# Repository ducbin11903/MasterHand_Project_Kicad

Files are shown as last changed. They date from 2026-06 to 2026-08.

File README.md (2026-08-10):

<p align="center" width="100%">
  
</p>

<h1 align="center">MOTOR CONTROL BOARD</h1>

<p align="center" width="100%">
  <a href="/actions/workflows/ci.yaml">
    CI Badge
  </a>
</p>

<p align="center" width="100%">
    
</p>

***

<p align="center">
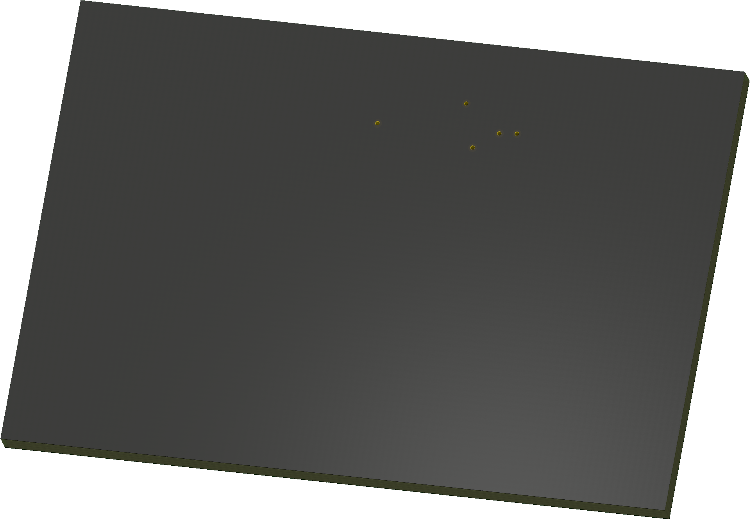
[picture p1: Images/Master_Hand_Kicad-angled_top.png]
3D Top Angled
  
&nbsp; &nbsp; &nbsp; &nbsp;
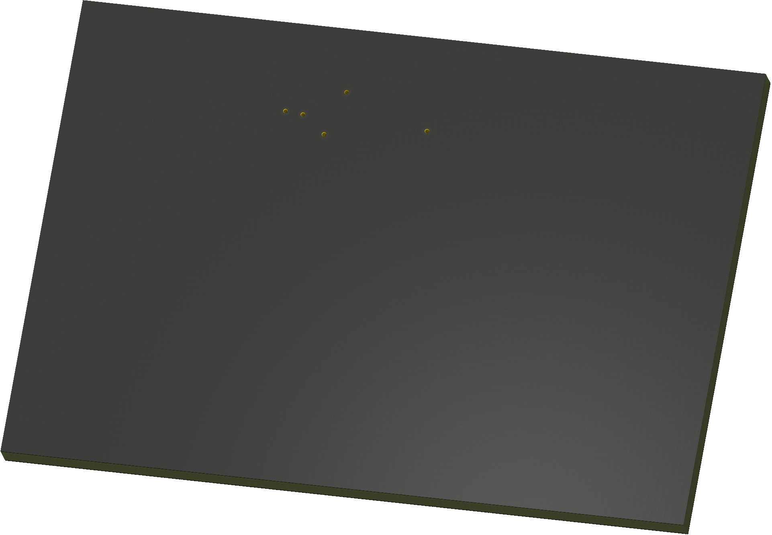
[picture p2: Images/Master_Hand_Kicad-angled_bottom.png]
3D Bottom Angled
  
</p>

***

## SPECIFICATIONS

| Parameter | Value | 
| --- | --- |
| Dimensions | 42.2 × 28.9 mm |

***

## DIRECTORY STRUCTURE

    .
    ├─ Computations       # Misc calculations
    ├─ HTML               # HTML files for generated webpage
    ├─ Images             # Pictures and renders
    │
    ├─ kibot_resources    # External resources for KiBot
    │  ├─ colors          # Color theme for KiCad
    │  ├─ fonts           # Fonts used in the project
    │  ├─ scripts         # External scripts used with KiBot
    │  └─ templates       # Templates for KiBot generated reports
    │
    ├─ kibot_yaml         # KiBot YAML config files
    ├─ KiRI               # KiRI (PCB diff viewer) files
    │
    ├─ lib                # KiCad footprint and symbol libraries
    │  ├─ 3d_models       # Component 3D models
    │  ├─ lib_fp          # Footprint libraries
    │  └─ lib_sym         # Symbol libraries
    │
    ├─ Logos              # Logos
    │
    ├─ Manufacturing      # Assembly and fabrication documents
    │  ├─ Assembly        # Assembly documents (BoM, pos, notes)
    │  │
    │  └─ Fabrication     # Fabrication documents (ZIP, notes)
    │     ├─ Drill Tables # CSV drill tables
    │     └─ Gerbers      # Gerbers
    │
    ├─ Report             # Reports for ERC/DRC
    ├─ Schematic          # PDF of schematic
    ├─ Templates          # Title block templates
    ├─ Testing
    │  └─ Testpoints      # Testpoints tables      
    │
    └─ Variants           # Outputs for assembly variants

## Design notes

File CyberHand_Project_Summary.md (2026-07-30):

# CyberHand — Motor Control & Main Board — Project Summary
_Cập nhật: 2026-07-14 · Dùng làm context cho Cowork / tài liệu repo_

---

## 1. Mô tả ngắn

Thiết kế 2 PCB cho bàn tay robot humanoid (CyberHand/CyberTUM) dùng 6 motor DC gear JGA12-N20B 6V: **Motor Control Board** và **MainBoard**, giao tiếp CAN FD + RS-422. Công cụ: **KiCad 9.0.1** + Git, hierarchy schematic, multi-channel reuse. Schematic đang vẽ theo cấu trúc sheet đánh số (vd sheet 6/19: "Power - Generation").

---

## 2. Hardware

### Motor Control Board
- 2× STM32G474RET6 (LQFP64, 170MHz), mỗi MCU điều khiển 3 motor
- 6× TB9051FTG H-bridge (VM 4.5–28V, 5A peak, AEC-Q100)
- 6× JGA12-N20B DC gear motor (stall 0.55A @6V, R cuộn ≈ 11Ω)
- 6× SS49E linear Hall sensor (ratiometric, cấp +A3V3)
- 2× TJA1051T CAN FD transceiver (VCC 5V), 120Ω termination 2 đầu bus
- 2× MAX3491 RS-422 transceiver (3.3V)
- 2× SHT31 (I2C 0x44, mỗi MCU 1 con)
- 2× USB Type-C riêng (DFU + CDC mỗi MCU) — **không nối VBUS vào rail 5V**, chỉ sense qua divider
- Crystal 8MHz HSE ×2, buzzer, 6× motor LED, battery voltage sensing

### MainBoard
- 1× STM32G474RET6, TCA9548A I2C mux, 5× FSR, ICM42688P IMU, 5× SK6812, TJA1051T, W5500 (SPI), crystal 32.768kHz

---

## 3. Power Architecture (ĐÃ CẬP NHẬT — thay thế plan LD39200 cũ)

```
LiPo 2S 7.4V / 2200mAh / 10C  (6.6–8.4V)
    │
[Polyfuse 15A] → [STPS20L60S Schottky] → [SMBJ10CA TVS]
    │
[BULK 330µF/25V polymer, ESR 20–40mΩ]  ← quyết định mới, xem mục 5
    │
    ├── +VBAT → 6× TB9051FTG VM  (+ 6× 10µF 1206 sát chân VM từng driver)
    │
    ├── U3 TPSM63603RDHR (buck module, 3A) → +5V
    │       ├── Tải 5V trực tiếp: TB9051 VCC ×6, TJA1051T ×2, LED/buzzer
    │       ├── U4 TPS62162DSG + L 2.2µH (buck 1A) → +3V3 (digital)
    │       │       └── STM32 ×2, MAX3491 ×2, SHT31, logic phụ
    │       └── U5 TLV75533PDBVR (LDO 500mA) → +A3V3 (analog)
    │               └── SS49E ×6, VDDA/VREF+ ×2, (SHT31 nếu chuyển sang analog rail)
```

Lý do kiến trúc 3 regulator: 3V3 digital từ buck (hiệu suất), A3V3 từ LDO riêng (sạch cho ADC).
SS49E ratiometric + VREF+ cùng rail A3V3 → sai số nguồn tự triệt tiêu.

### Việc còn phải xác nhận trên sheet Power - Generation (6/19)
- [ ] **FB pin TPS62162 (bản fixed 3.3V) phải nối GND** — không để floating
- [ ] Xác nhận net **F_VIN_3V3 lấy từ +5V** (TLV75533 VIN max 5.5V, không được ăn VBAT)
- [ ] Nối **VLDOIN (pin 22) của TPSM63603 → VOUT** (VOUT=5V ≥ 3.3V, tăng hiệu suất)
- [ ] Tính divider R1/R4 trên EN/SYNC cho **UVLO ≈ 6.0–6.2V** (bảo vệ LiPo, có hysteresis)
- [ ] **EN_3V3 lấy từ PG của U3** (pull-up 100k lên 5V, PG open-drain) → sequencing 5V trước, 3V3+A3V3 sau
- [ ] Điền value tụ: U3 in 2×10µF/25V + 100nF; U3 out 3–4×22µF/10V (theo bảng datasheet ứng R5/RT); VCC 1µF; CBOOT 100nF+RBOOT; U4 in 10µF/out 22µF, L1 Isat ≥ 1.5A; U5 in/out 1µF (out 10µF càng tốt)
- [ ] FB4 sau LDO: giữ thì thêm 10µF+100nF tại VDDA/VREF+; bỏ cũng được
- [ ] AGND của U3 nối PGND single-point theo layout guideline TI

---

## 4. Power Budget (ĐÃ TÍNH LẠI)

Phương pháp: I_avg = Σ Typ tại điều kiện thật; I_peak = Σ Max @T_max, chỉ tải đồng thời. Chọn regulator ≥ 1.5–2× peak.

| Rail | Nguồn | Avg (typ) | Peak (max) | Định mức | Ghi chú |
|---|---|---|---|---|---|
| VBAT 7.4V | LiPo qua protection | ~1.25A | ~3.75A (duty≤71%) / **4.6A nếu duty 100% @8.4V** | 22A (10C) | 6 motor stall = worst case |
| +5V | TPSM63603 | ~180mA | ~610mA | 3A | TB9051 VCC + TJA1051 dominant + đầu vào U4/U5 |
| +3V3 | TPS62162 | ~113mA | ~340mA | 1A | STM32 ×2 (~60mA max/con gồm peripheral+analog) + MAX3491 TX |
| +A3V3 | TLV75533 | ~40mA | ~67mA | 500mA | **Sửa budget cũ 8.3/15.6mA — thiếu SS49E ~6mA/con** |

Ghi chú quan trọng:
- **Stall N20 scale theo áp**: 0.55A là @6V. Full duty @8.4V → 0.77A/motor. Quyết định: giới hạn duty max ≈ 71% trong firmware HOẶC tính budget theo 4.6A. Ghi giả định vào tài liệu.
- STM32G474: I_DD bảng datasheet đo "all peripherals disabled" — phải cộng Table 35 (peripheral µA/MHz: TIM1/8 ~10.8, FDCAN 22.2, ADC 6.2...) ≈ +13mA @170MHz, và analog (OPAMP 1.3–2.2mA/con, ADC I_DDA...) ≈ +6mA. Tổng thực tế ~60mA max/con @85°C.
- MAX3491: I_CC datasheet KHÔNG gồm dòng lái bus (±2V/120Ω ≈ 20–33mA, cộng riêng). TJA1051: ĐÃ gồm, lấy hàng dominant (~70mA max) cho peak.
- LED: dòng do điện trở chọn, không lấy từ datasheet LED.

---

## 5. Bulk cap VBAT (quyết định + phương pháp)

**Chọn: 1× polymer 330µF / 16–25V, ESR 20–40mΩ** (kiểu OS-CON/SP-Cap) ngay sau Schottky, + 6× 10µF ceramic 1206 sát VM từng TB9051.

Cơ sở tính (L_lead ≈ 0.5µH, ΔI = 3.3A, ΔV cho phép ≈ 0.3V):
- C ≥ L·(ΔI/ΔV)² = 0.5µ × (3.3/0.3)² ≈ 60µF tối thiểu → ×3–5 margin → 330µF
- ESR_opt ≈ √(L/C) = √(0.5µ/330µ) ≈ 39mΩ (damping ζ ≈ 0.5–1; toàn ceramic ESR 2mΩ sẽ ringing)
- Ripple rating ≥ ~1A RMS @100kHz; voltage rating 25V (TVS clamp ~17V)

Mô phỏng (load step 0→3.3A qua 0.5µH, pin 40mΩ + polyfuse + Schottky):
| Cấu hình | Vmin tại board | Kết quả |
|---|---|---|
| Chỉ 30µF ceramic | 6.59V | droop 0.46V + ringing mạnh |
| +100µF/50mΩ | 6.84V | ổn |
| **+330µF/30mΩ polymer** | **6.89V** | **droop 0.16V, tắt gọn — CHỌN** |
| +330µF ceramic 2mΩ | 6.88V | droop OK nhưng ring kéo dài |

File mô phỏng trong repo/tài liệu: `bulk_cap_vbat.cir` (LTspice/ngspice), `bulk_cap_sim.py`. Validate board thật: load step + oscilloscope với ground spring tại chân tụ.

---

## 6. Firmware STM32G474 — Motor Control (không đổi)

- TIM1/TIM8 → PWM 20kHz ×6 motor; **duty max ≈ 71% nếu chọn phương án giới hạn stall**
- TIM2/3/4 → encoder mode; TIM6 → control loop 20kHz
- ADC injected trigger từ TIM1, simultaneous ADC1+ADC2 đọc OCM
- OPAMP + COMP → TIM1 BKIN (hardware overcurrent)
- FDCAN1 1Mbps (3 node), DMA (ADC circular, UART TX), EXTI (DIAG, S_ENC)
- I2C SHT31 (0x44), USB CDC/DFU (PA11/PA12), HSE 8MHz, CRC hardware

---

## 7. Giao tiếp giữa các board (không đổi)

MainBoard ↔ CAN FD 1Mbps ↔ Motor Control (MCU1+MCU2); RS-422; Ethernet/W5500 → ROS2.
CAN: 3 node, 3× TJA1051T, 1 bus CANH/CANL, 120Ω tại 2 đầu vật lý.

---

## 8. KiCad & Git

- KiCad 9.0.1, Git version control, mỗi sub-sheet 1 file riêng
- Cấu trúc: `CyberHand/{Motor_Control, Main_Board, Library, Datasheets}` — sheets/ chứa Power_Source, Motor_Driver (×6 reuse), Motor_Controller_1/2, CAN_Transceiver, RS422, Hall_Sensor, SHT31
- `.gitignore`: `*.kicad_prl`, `*-backups/`, `fp-info-cache`
- Commit convention: `[MOTOR] ...`, `[MAIN] ...`

---

## 9. Trạng thái hiện tại

### Motor Control Board
- ✅ Block diagram, component selection
- ✅ Power budget — **đã tính lại theo mục 4**
- ✅ Power - Generation schematic (sheet 6/19) draft — **còn checklist mục 3**
- ✅ Motor Driver sub-sheet draft (TB9051FTG), MCU schematic draft
- ✅ Bulk cap: đã chọn + mô phỏng (mục 5)
- ⬜ Hoàn thiện Power path protection sub-sheet (Polyfuse + Schottky + TVS + bulk 330µF)
- ⬜ CAN transceiver sub-sheet, RS-422 sub-sheet, Hall SS49E sub-sheet, SHT31 sub-sheet
- ⬜ PCB layout (note: FB trace tránh SW node, minimize SW loop, AGND single-point)

### MainBoard
- ✅ Block diagram
- ⬜ Schematic, PCB layout

---

## 10. Tham khảo nhanh

```
Motor:      JGA12-N20B 6V, stall 0.55A @6V (0.77A @8.4V full duty), R ≈ 11Ω
Driver:     TB9051FTG, VM 4.5–28V, 5A peak, VCC 5V (UV detect 3.5V)
MCU:        STM32G474RET6, 170MHz boost, ~60mA max thực tế/con @85°C
Buck 5V:    TPSM63603RDHR, 3A — nối VLDOIN→VOUT, UVLO qua EN divider ≈ 6.0V
Buck 3V3:   TPS62162DSG, 1A, L 2.2µH, FIXED → FB nối GND
LDO A3V3:   TLV75533PDBVR, 500mA, VIN max 5.5V (chỉ ăn từ +5V)
CAN:        TJA1051T, dominant ~70mA max (đã gồm bus drive)
RS-422:     MAX3491 — I_CC chưa gồm dòng lái bus (+20–33mA/driver khi TX)
Hall:       SS49E ratiometric, ~6mA typ/10mA max mỗi con, cấp A3V3
Bulk:       Polymer 330µF/25V ESR 20–40mΩ + 6×10µF sát VM
Nguồn:      LiPo 2S 7.4V/2200mAh/10C, protection: Polyfuse 15A + STPS20L60S + SMBJ10CA
Sequencing: VBAT → 5V → (PG U3) → 3V3 + A3V3
```

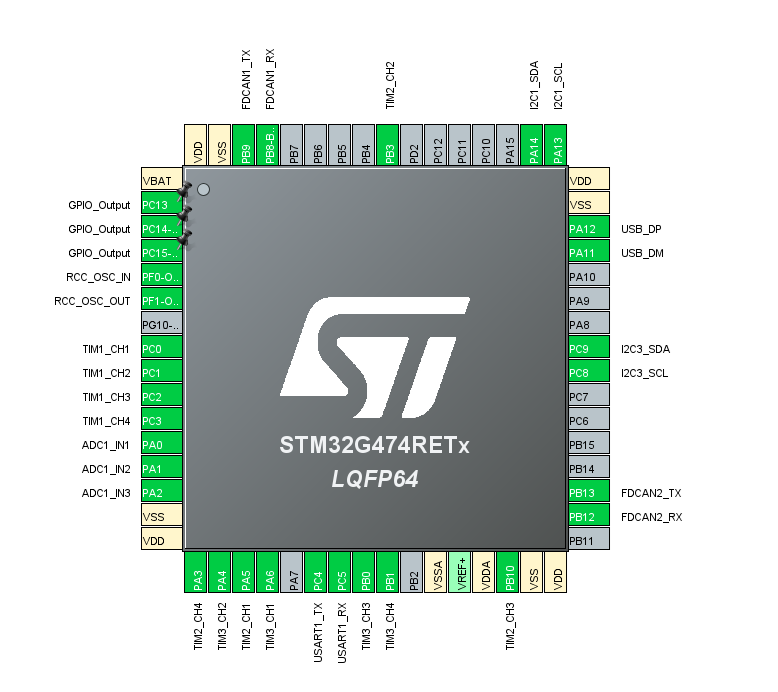
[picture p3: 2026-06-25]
STM32 Pinout.png

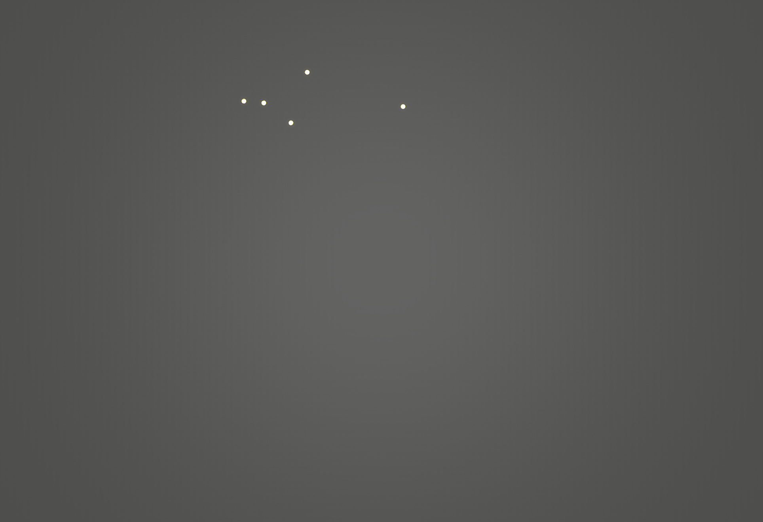
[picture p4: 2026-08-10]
Images/Master_Hand_Kicad-bottom.png

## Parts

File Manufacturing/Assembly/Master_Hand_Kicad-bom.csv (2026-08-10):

Row | Quantity Per PCB | References | Value | Datasheet | Footprint | Description | Manufacturer | Manufacturer Part Number | Supplier Part Number
1 | 27 | C2 C3 C4 C5 C7 C11 C13 C15 C17 C18 C23 C44 C45 C46 C47 C49 C50 C53 C54 C57 C58 C61 C62 C65 C66 C69 C70 | 100nF 50V 0402 | https://lcsc.com/product-detail/Multilayer-Ceramic-Capacitors-MLCC-SMD-SMT_YAGEO-CC0402KRX7R9BB104_C131394.html | C0402 | CAP CER 100nF 50V X7R 0402 CAP CER 1206 CAP CER 0603 CAP CER 0402 | YAGEO(国巨)
2 | 6 | C51 C55 C59 C63 C67 C71 | 470nF 16V 0402 |  | C0402 | CAP CER 0402
3 | 9 | C1 C8 C9 C12 C14 C16 C21 C31 C32 | 1uF 10V 0402 | https://www.lcsc.com/datasheet/C7500381.pdf | C0402 | CAP CER 1uF 10V X7R 0402 CAP CER 0402 CAP CER 1206 | YAGEO(国巨)
4 | 4 | C25 C26 C27 C28 | 2.2uF 100V 0402 |  | C0402 | CAP CER 0402
5 | 10 | C6 C10 C19 C20 C48 C52 C56 C60 C64 C68 | 4.7uF 16V 0402 | https://www.lcsc.com/datasheet/C723999.pdf | C0402 | CAP CER 4.7uF 16V X5R 0402 CAP CER 1206 CAP CER 0402 | YAGEO(国巨)
6 | 13 | C22 C29 C30 C34 C35 C36 C37 C38 C39 C40 C41 C42 C43 | 10uF 25V 1206 |  | C1206 | CAP CER 1206 CAP CER 0603 | YAGEO(国巨)
7 | 1 | C24 | 22uF 10V 1206 |  | C1206 | CAP CER 1206
8 | 1 | C33 | 25SVPF330M | https://lcsc.com/product-detail/Solid-Polymer-Electrolytic-Capacitor_PANASONIC_25SVPF330M_330uF-25V_C178367.html | CAP-SMD_BD10.0-L10.3-W10.3-LS11.0-FD | CP 330uF ±20% 25V SMD | PANASONIC(松下)
9 | 1 | D1 | SMAJ12A | https://lcsc.com/product-detail/TVS_Littelfuse_SMAJ12A_SMAJ12A_C148213.html | SMA_L4.3-W2.6-LS5.2-RD | TVS DIODE 12VWM 19.9VC DO-214AC(SMA) | Littelfuse(美国力特)
10 | 4 | FB1 FB2 FB3 FB4 | 1k @ 100MHz | https://www.lcsc.com/datasheet/C52178237.pdf | L0805 | 300mΩ 1 ±25% 1kΩ@100MHz 0805 Ferrite Beads and Chips RoHS | PROD(谱罗德)
11 | 8 | J1 J2 J3 J4 J5 J6 J7 | DC-044A-20A | https://lcsc.com/product-detail/DC-Connectors_1-65-2-0-DCseat-11-6mm-10-1mm_C129006.html | DC-IN-TH_DC-044A-20A | CONN PWR JACK 2mm x 5.9mm TH R/A CONN HEADER SMD 9POS 1mm | 韩国韩荣 JST
12 | 1 | L1 | ANR3015T2R2M | https://www.lcsc.com/datasheet/C6364793.pdf | IND-SMD_L3.0-W3.0_SMNR3015 | 2.2uH 2A | APV(爱普微)
13 | 2 | Q1 Q2 | HV10N03 | https://www.lcsc.com/datasheet/C53329063.pdf | SOT-89-3_L4.5-W2.5-P1.50-LS4.0-BR | 3W 30V 10A 1.5V 18mΩ@10V 1 N-channel N-Channel SOT-89 Single FETs, MOSFETs RoHS | R+O(宏嘉诚)
14 | 6 | R7 R10 R13 R16 R19 R22 | 1R 0.1% 0402 |  | R0402 | RES SMD 0402
15 | 6 | R9 R12 R15 R18 R21 R24 | 510R 0.1% 0402 |  | R0402 | RES SMD 0402
16 | 8 | R2 R4 R8 R11 R14 R17 R20 R23 | 10K 0.1% 0402 |  | R0402 | RES 0.1% 0402 RES SMD 0402
17 | 1 | R5 | 13K 0.1% 0402 |  | R0402 | RES 0.1% 0402
18 | 1 | R1 | 40.2K 0.1% 0402 |  | R0402 | RES 0.1% 0402
19 | 1 | R3 | 41.2K 0.1% 0402 |  | R0402 | RES 0.1% 0402
20 | 1 | R6 | 100K 0.1% 0603 | https://www.lcsc.com/datasheet/C4107493.pdf | R0603 | RES 0.1% 0603 | YAGEO(国巨)
21 | 2 | U8 U9 | LM74700QDBVRQ1 | https://www.lcsc.com/datasheet/C2941042.pdf | SOT-23-6_L2.9-W1.6-P0.95-LS2.8-BL | Low IQ Battery Reverse Protection Ideal Diode Controller | TI(德州仪器)
22 | 4 | U1 U2 U6 U7 | STM32G474RET6 | https://lcsc.com/product-detail/No-specification-for-star-making-plan_STMicroelectronics-STM32G474RET6_C521608.html | LQFP-64_L10.0-W10.0-P0.50-LS12.0-BL | Arm Cortex-M4 32-bit MCU+FPU, 170 MHz / 213 DMIPS, 128 KB SRAM, rich analog, math acc, 184 ps 12 chan Hi-res timer | ST(意法半导体)
23 | 6 | U10 U11 U12 U13 U14 U15 | TB9051FTG,EL | https://www.lcsc.com/datasheet/C2150635.pdf | UQFN-28_L6.0-W6.0-P0.65-BL-EP4.0 | UQFN-28-EP(6x6) Motor Drivers, Controllers RoHS | TOSHIBA(东芝)
24 | 1 | U5 | TLV75533PDBVR | https://lcsc.com/product-detail/Low-Dropout-Regulators-LDO_Texas-Instruments-TI-TLV75533PDBVR_C404027.html | SOT-23-5_L3.0-W1.7-P0.95-LS2.8-BR | 500mA, high PSRR, low IQ, low-dropout regulator with enable functionality | TI(德州仪器)
25 | 1 | U4 | TPS62162DSG | https://lcsc.com/product-detail/DC-DC-Converters_TI_TPS62162DSG_TPS62162DSG_C40256.html | WSON-8_L2.0-W2.0-P0.50-TL-EP | 3V-17V 1A Step-Down Converters with DCS-ControlTM | TI(德州仪器)
26 | 1 | U3 | TPSM63603RDHR | https://www.ti.com/lit/ds/symlink/tpsm63603.pdf | QFN-30_L6.0-W4.0-P0.50_TLVM13630RDHR | Power module with 3V to 36V input 1V to 16V output and 3A current | TI(德州仪器)

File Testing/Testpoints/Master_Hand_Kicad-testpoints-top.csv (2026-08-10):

Ref. | Net | X [mm] | Y [mm]
TP1 |  | -64.00 | 106.00
TP2 |  | -64.00 | 106.00
TP3 |  | -64.00 | 106.00
TP4 |  | -64.00 | 106.00
TP5 |  | -64.00 | 106.00
TP6 |  | -64.00 | 106.00
TP7 |  | -64.00 | 106.00
TP8 |  | -64.00 | 106.00
TP9 |  | -64.00 | 106.00
TP10 |  | -64.00 | 106.00
TP11 |  | -64.00 | 106.00
TP12 |  | -64.00 | 106.00
TP13 |  | -64.00 | 106.00
TP14 |  | -64.00 | 106.00
TP15 |  | -64.00 | 106.00
TP16 |  | -64.00 | 106.00
TP17 |  | -64.00 | 106.00
TP18 |  | -64.00 | 106.00
TP19 |  | -64.00 | 106.00
TP20 |  | -64.00 | 106.00
TP21 |  | -64.00 | 106.00
TP22 |  | -64.00 | 106.00
TP23 |  | -64.00 | 106.00
TP24 |  | -64.00 | 106.00
TP25 |  | -64.00 | 106.00
TP26 |  | -64.00 | 106.00
TP27 |  | -64.00 | 106.00
TP28 |  | -64.00 | 106.00
TP29 |  | -64.00 | 106.00
TP30 |  | -64.00 | 106.00
TP31 |  | -64.00 | 106.00
TP32 |  | -64.00 | 106.00
TP33 |  | -64.00 | 106.00
TP34 |  | -64.00 | 106.00
TP35 |  | -64.00 | 106.00
TP36 |  | -64.00 | 106.00
TP37 |  | -64.00 | 106.00
TP38 |  | -64.00 | 106.00
TP39 |  | -64.00 | 106.00
TP40 |  | -64.00 | 106.00
TP41 |  | -64.00 | 106.00
TP42 |  | -64.00 | 106.00
TP43 |  | -64.00 | 106.00
TP44 |  | -64.00 | 106.00
TP45 |  | -64.00 | 106.00
TP46 |  | -64.00 | 106.00
TP47 |  | -64.00 | 106.00
TP48 |  | -64.00 | 106.00
TP49 |  | -64.00 | 106.00
TP50 |  | -64.00 | 106.00

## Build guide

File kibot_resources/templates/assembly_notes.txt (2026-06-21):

ASSEMBLY NOTES (UNLESS OTHERWISE SPECIFIED)

1)	DO NOT POPULATE PARTS ARE MARKED WITH A RED CROSS.

2)	DO NOT POPULATE PARTS ARE NOT PRESENT IN THE BOM.

3)	IF CONFLICTING INFORMATION IS FOUND BETWEEN THE ASSEMBLY
	FILE AND BOM, BOM SHOULD BE USED AS THE MAIN SOURCE.

4)	CONFORMAL COATING IS NOT REQUIRED.

5)	DOT IDENTIFIES PIN #1 LOCATION AND DEVICE ORIENTATION
	WHEN VIEWED FROM THE TOP.

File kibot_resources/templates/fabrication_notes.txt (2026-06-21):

FABRICATION NOTES (UNLESS OTHERWISE SPECIFIED)

1)	FABRICATE PER IPC-6012A CLASS 2.

2)	OUTLINE DEFINED IN SEPARATE GERBER FILE WITH
	"Edge_Cuts.GBR" SUFFIX.

	DIMENSIONS OF CIRCUMSIZED RECTANGLE SHOWN ON THIS
	DRAWING FOR REFERENCE ONLY.

3)	SEE SEPARATE DRILL FILES WITH ".DRL" SUFFIX 
	FOR HOLE LOCATIONS.

	SELECTED HOLE LOCATIONS SHOWN ON THIS DRAWING 
	FOR REFERENCE ONLY.

4)	SURFACE FINISH: ${pcb_finish_cap}

5)	SOLDERMASK ON BOTH SIDES OF THE BOARD SHALL 
	BE LPI, COLOR ${solder_mask_color_text_cap}.

6)	SILK SCREEN LEGEND TO BE APPLIED PER LAYER 
	STACKUP USING ${silk_screen_color_text_cap} NON-CONDUCTIVE EPOXY INK.

7)	ALL VIAS ARE TENTED ON BOTH SIDES UNLESS 
	SOLDERMASK OPENED IN GERBER.

8)	VENDOR SHOULD FOLLOW ROHS COMPLIANT PROCESS 
	AND Pb FREE FOR MANUFACTURING

9)	PCB MATERIAL REQUIREMENTS:

	A.	FLAMMABILITY RATING MUST MEET OR EXCEED 
		UL94V-0 REQUIREMENTS.
	B.	Tg 170 C OR EQUIVALENT.
	C.	EQUIVALENT MATERIAL SHALL BE RoHS COMPLIANT, 
		HALOGEN FREE AND APPROVED BY ${COMPANY_cap}.

10)	DESIGN GEOMETRY MINIMUM FEATURE SIZES:

	BOARD SIZE				${bb_w_mm} × ${bb_h_mm} mm
	BOARD THICKNESS		${thickness_mm} mm
	TRACE WIDTH			${track_mm} mm
	TRACE TO TRACE		${clearance_mm} mm
	MIN. HOLE (PTH)			${drill_pth_real_mm} mm
	MIN. HOLE (NPTH)		${drill_npth_real_mm} mm
	ANNULAR RING			${oar_mm} mm
	COPPER TO HOLE		${c2h_mm} mm
	COPPER TO EDGE		${c2e_mm} mm
	HOLE TO HOLE			${h2h_mm} mm
#?stackup and impedance_controlled

#?stackup and impedance_controlled
11)	REFER TO IMPEDANCE TABLE FOR IMPEDANCE CONTROL REQUIREMENTS.
#?stackup and impedance_controlled

#?stackup and impedance_controlled
12)	CONFIRM SPACE WIDTHS AND SPACINGS.

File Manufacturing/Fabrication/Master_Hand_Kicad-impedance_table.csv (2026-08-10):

Transmission Line | Impedance [ohms] | Tolerance [ohms] | Layer | Trace Width [mm] | Gap [mm] | Ref. Layers
Edge-Coupled Coated Microstrip | 100 | ±10 % | L1 | 0.2032 | 0.28 | L2

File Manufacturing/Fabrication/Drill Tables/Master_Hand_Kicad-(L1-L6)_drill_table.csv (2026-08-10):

Count | Hole Size | Plated | Hole Shape | Drill Layer Pair | Hole Type
7 | 0.25mm (9.84mils) | PTH | Round | L1 (Sig, PWR) - L6 (Sig, PWR) | Via
Total 7

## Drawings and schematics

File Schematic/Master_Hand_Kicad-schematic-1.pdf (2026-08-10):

# Rev

# YYYY-MM-DD

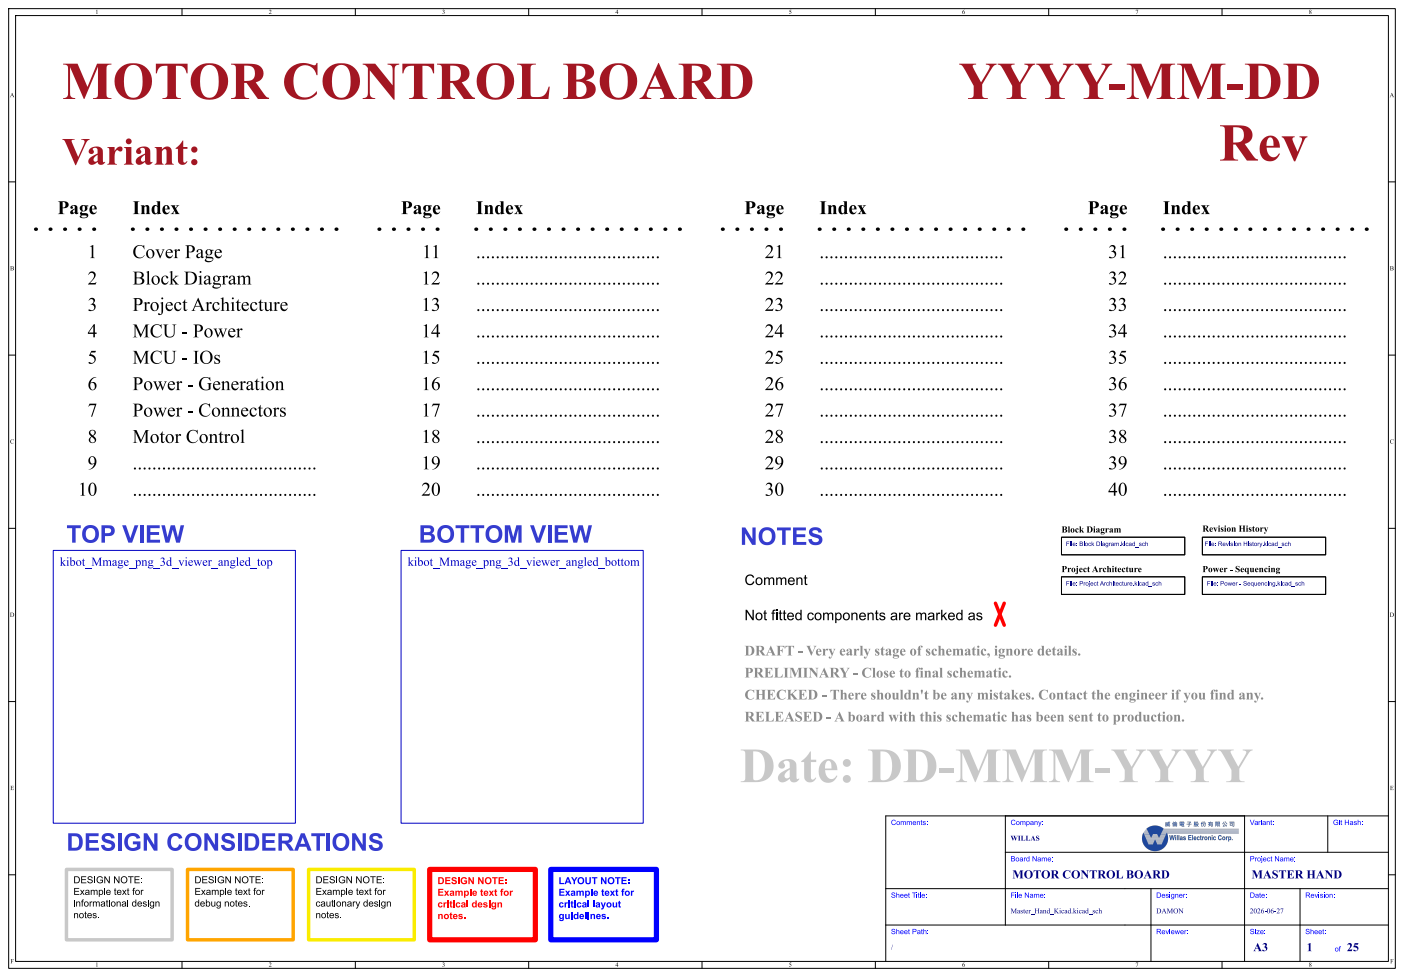
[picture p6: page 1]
Sheet: of 25; Size: A3; Date:; Revision: Project Name: 2026-06-27 Reviewer: Designer:; Master_Hand_Kicad.kicad_sch; DAMON; Board Name: Company:; Variant: WILLAS MOTOR CONTROL BOARD; MASTER HAND; Sheet Title:; File Name:; /Sheet Path: Comments:; Git Hash: BlockDiagram; ProjectArchitecture; File: Project Architecture.kicad_sch; Power- Sequencing; RevisionHistory; kibot_Mmage_png_3d_viewer_angled_top; kibot_Mmage_png_3d_viewer_angled_bottom; Page; Index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

MOTOR CONTROL BOARD
Variant:

CHECKED - Thereshouldn'tbeanymistakes.Contacttheengineerif youfindany. ......................................

...................................... Date:DD-MMM-YYYY

File: Block Diagram.kicad_sch

File: Revision History.kicad_sch

File: Power - Sequencing.kicad_sch

Not fitted components are marked as

DRAFT - Veryearlystageof schematic,ignoredetails.
PRELIMINARY - Closetofinal schematic.

DESIGN NOTE:
Example text for
informational design
notes.

debug notes.

cautionary design

critical design

LAYOUT NOTE:
critical layout
guidelines.

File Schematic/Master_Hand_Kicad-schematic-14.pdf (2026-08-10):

# {MD1}+3.3V

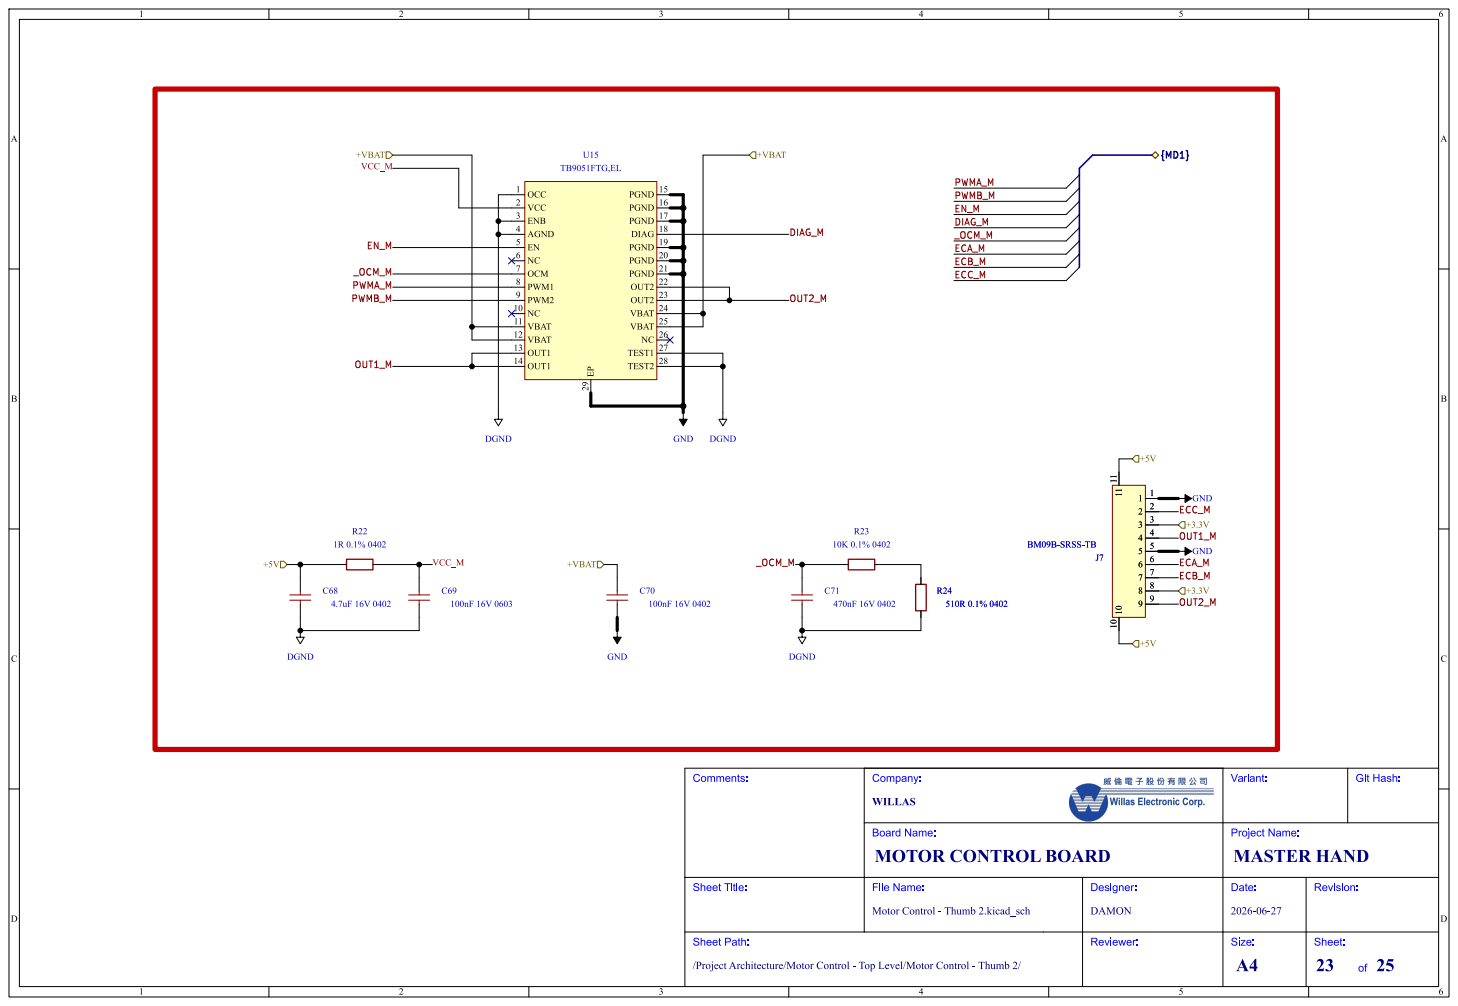
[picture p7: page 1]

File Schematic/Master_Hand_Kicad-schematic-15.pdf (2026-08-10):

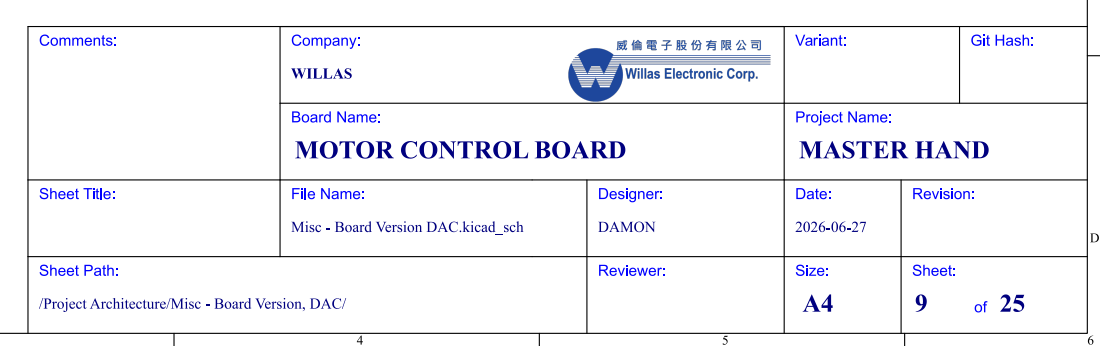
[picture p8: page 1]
Sheet: of 25; Size: A4; Date:; Revision: Project Name: 2026-06-27 Reviewer: Designer: Misc - BoardVersionDAC.kicad_sch; DAMON; Board Name: Company:; Variant: WILLAS MOTOR CONTROL BOARD; MASTER HAND; Sheet Title:; File Name:; /ProjectArchitecture/Misc- BoardVersion,DAC/ Sheet Path: Comments:; Git Hash:

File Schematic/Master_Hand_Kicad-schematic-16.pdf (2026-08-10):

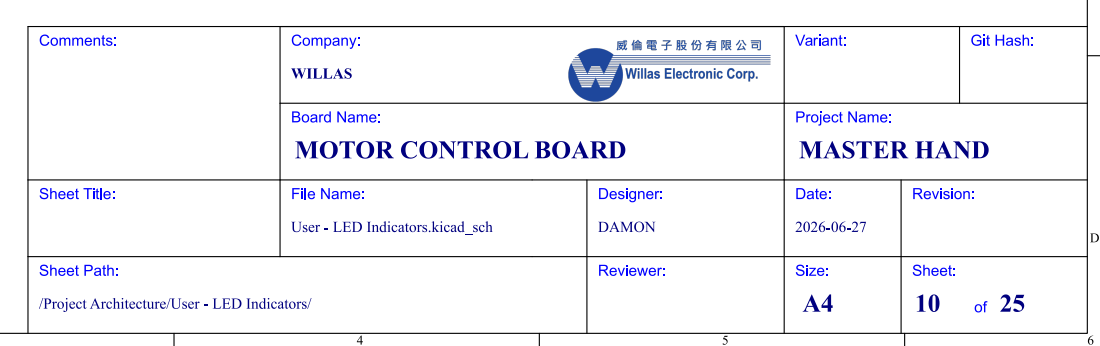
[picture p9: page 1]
Sheet: of 25; Size: A4; Date:; Revision: Project Name: 2026-06-27 Reviewer: Designer: User- LED Indicators.kicad_sch; DAMON; Board Name: Company:; Variant: WILLAS MOTOR CONTROL BOARD; MASTER HAND; Sheet Title:; File Name:; /ProjectArchitecture/User- LED Indicators/ Sheet Path: Comments:; Git Hash:

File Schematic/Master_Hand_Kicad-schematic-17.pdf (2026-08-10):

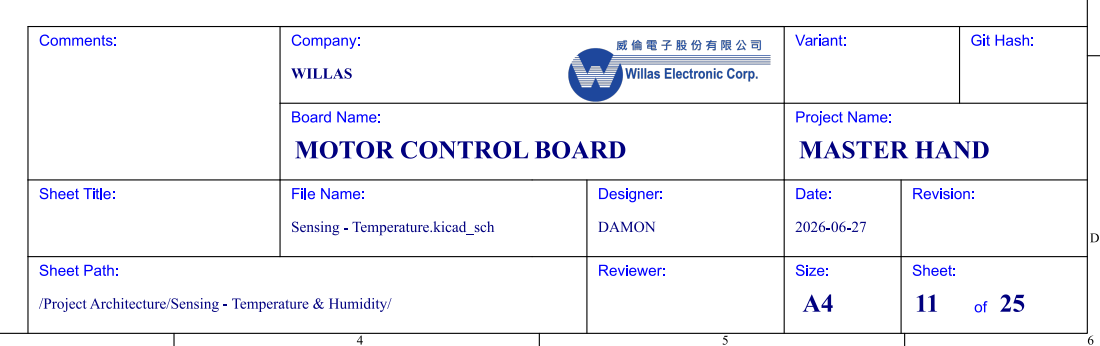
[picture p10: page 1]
Sheet: of 25; Size: A4; Date:; Revision: Project Name: 2026-06-27 Reviewer: Designer:; Sensing- Temperature.kicad_sch; DAMON; Board Name: Company:; Variant: WILLAS MOTOR CONTROL BOARD; MASTER HAND; Sheet Title:; File Name:; /ProjectArchitecture/Sensing- Temperature& Humidity/ Sheet Path: Comments:; Git Hash:

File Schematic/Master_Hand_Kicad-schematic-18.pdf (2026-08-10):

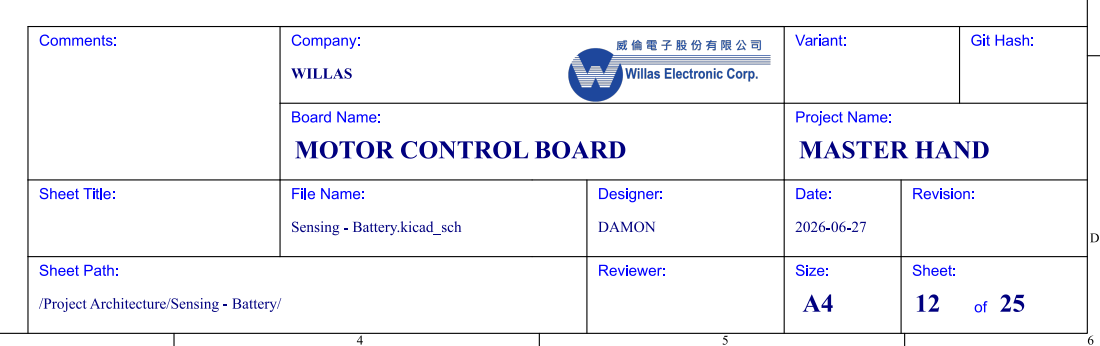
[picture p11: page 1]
Sheet: of 25; Size: A4; Date:; Revision: Project Name: 2026-06-27 Reviewer: Designer:; Sensing- Battery.kicad_sch; DAMON; Board Name: Company:; Variant: WILLAS MOTOR CONTROL BOARD; MASTER HAND; Sheet Title:; File Name:; /ProjectArchitecture/Sensing- Battery/ Sheet Path: Comments:; Git Hash:

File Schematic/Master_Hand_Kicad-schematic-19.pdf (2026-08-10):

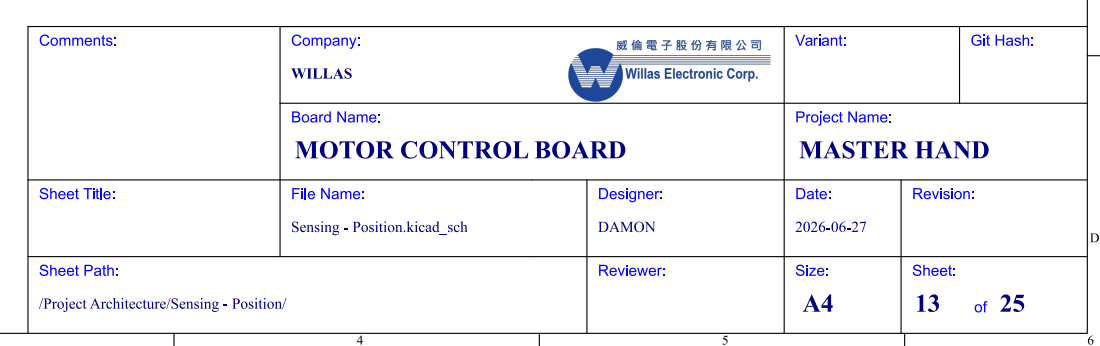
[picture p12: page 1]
Sheet: of 25; Size: A4; Date:; Revision: Project Name: 2026-06-27 Reviewer: Designer:; Sensing- Position.kicad_sch; DAMON; Board Name: Company:; Variant: WILLAS MOTOR CONTROL BOARD; MASTER HAND; Sheet Title:; File Name:; /ProjectArchitecture/Sensing- Position/ Sheet Path: Comments:; Git Hash:

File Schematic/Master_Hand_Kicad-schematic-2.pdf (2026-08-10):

## SECTION

1

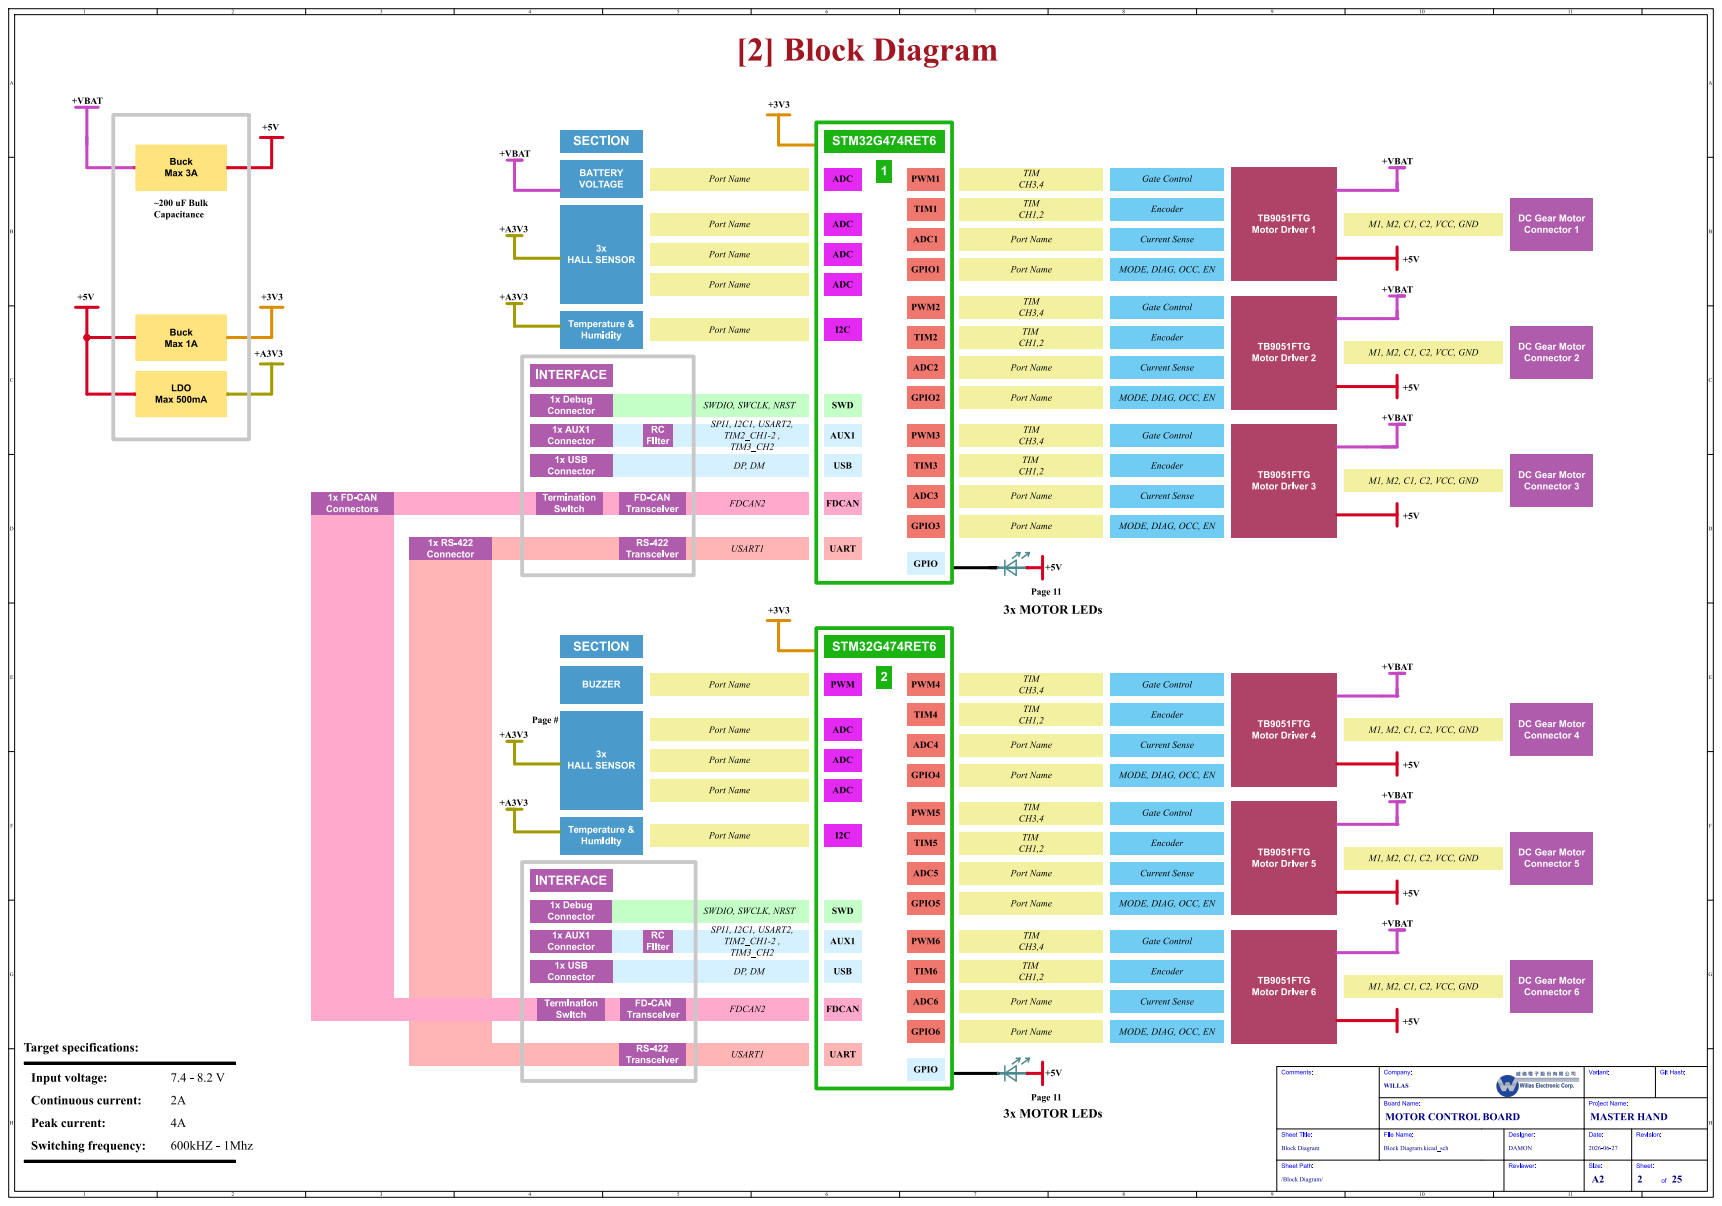
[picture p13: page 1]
Sheet: of 25; Size: A2; Date:; Revision: Project Name: 2026-06-27 Reviewer: Designer: Block Diagram.kicad_sch; DAMON; Board Name: Company:; Variant: WILLAS MOTOR CONTROL BOARD; MASTER HAND; Sheet Title:; File Name:; Comments:; Git Hash:; RC Filter; Encoder; FD-CAN Transceiver; SECTION; RS-422 Transceiver; FDCAN2; SPI1,I2C1,USART2, TIM2_CH1-2, TIM3_CH2; SWDIO,SWCLK,NRST; GateControl; 1x AUX1 Connector; Termination Switch; USART1; TIM1; INTERFACE; PWM1; 1x USB Connector; Continuouscurrent: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

DC Gear Motor
Connector 1

MODE,DIAG, OCC,EN

Connector 2

Connector 3

Connector 4

Connector 5

Connector 6

/Block Diagram/ Sheet Path: Block Diagram

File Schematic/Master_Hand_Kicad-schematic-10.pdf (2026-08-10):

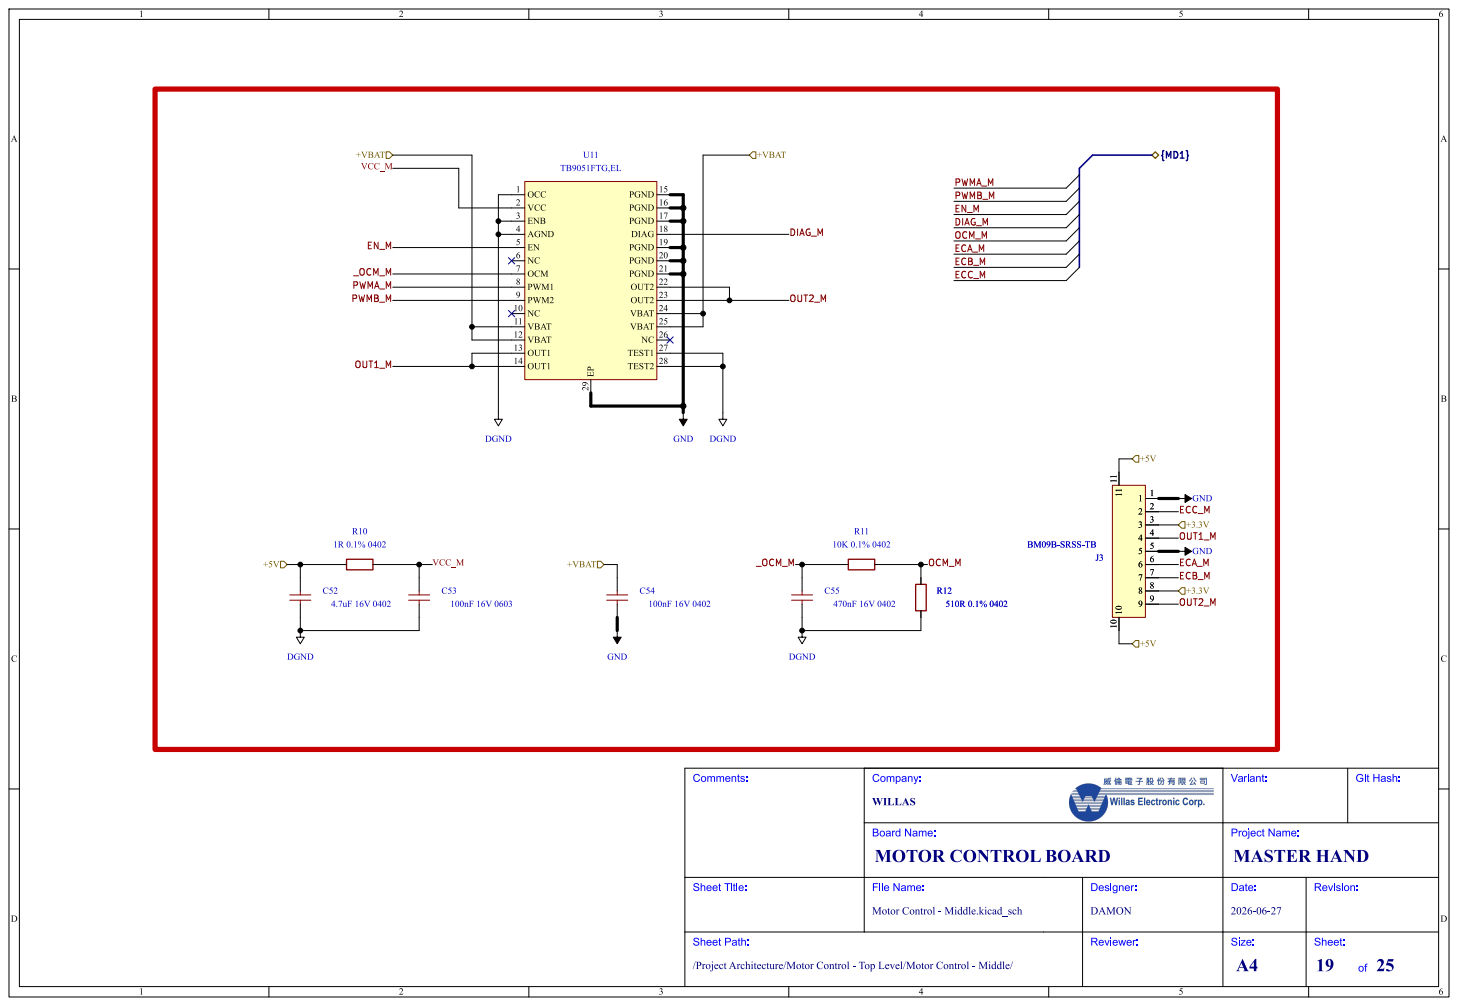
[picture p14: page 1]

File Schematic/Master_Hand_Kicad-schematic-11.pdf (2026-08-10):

# {MD1}ECC_M

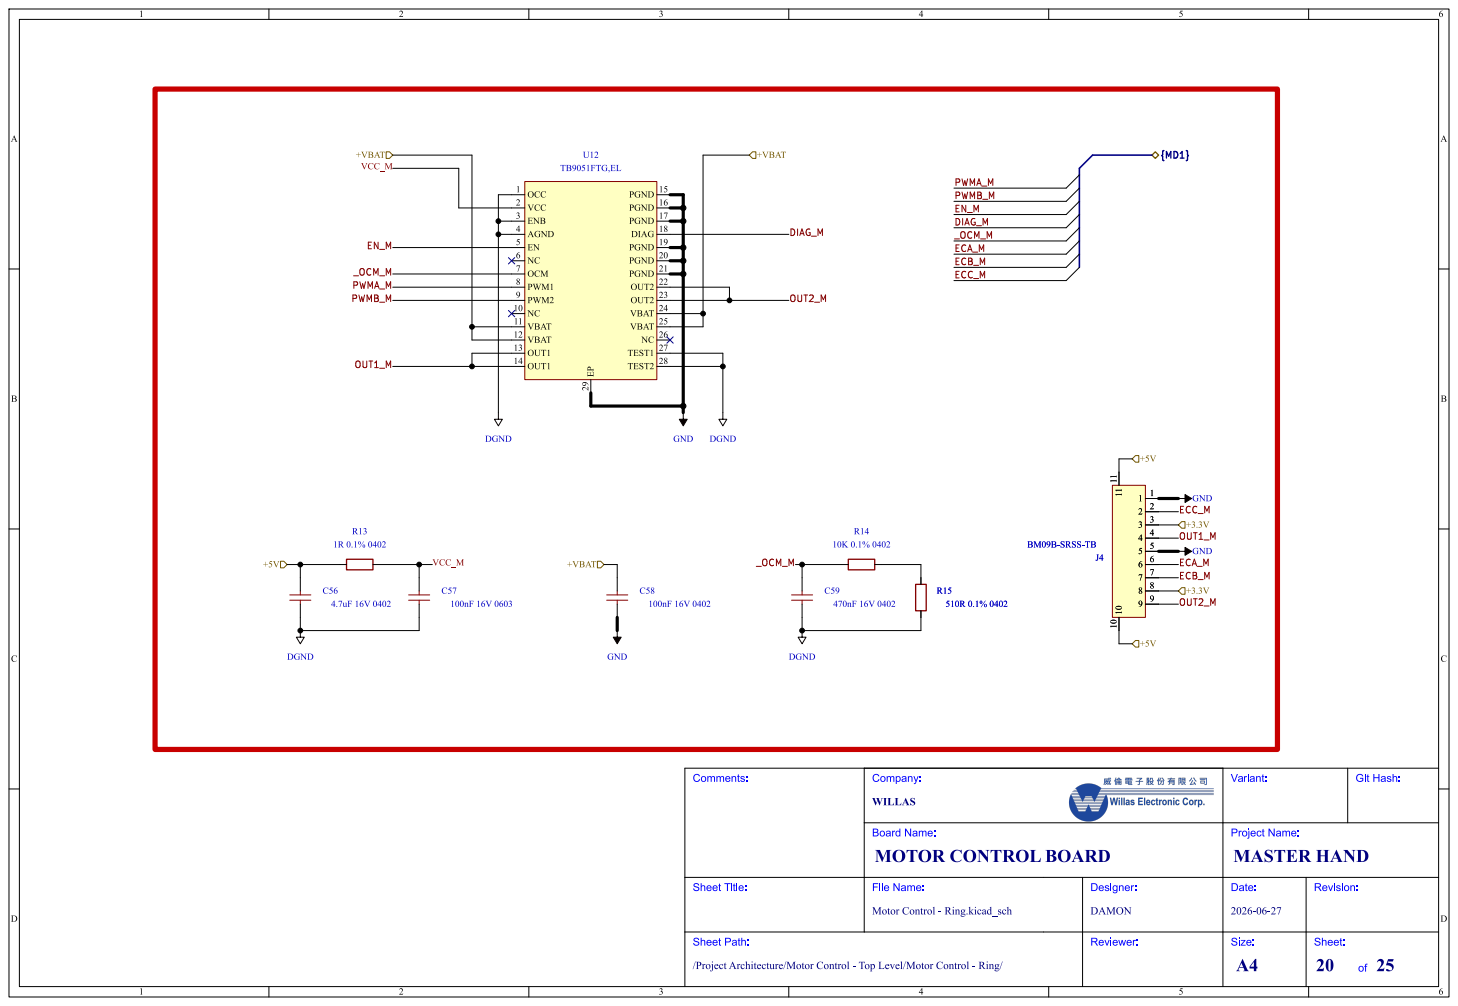
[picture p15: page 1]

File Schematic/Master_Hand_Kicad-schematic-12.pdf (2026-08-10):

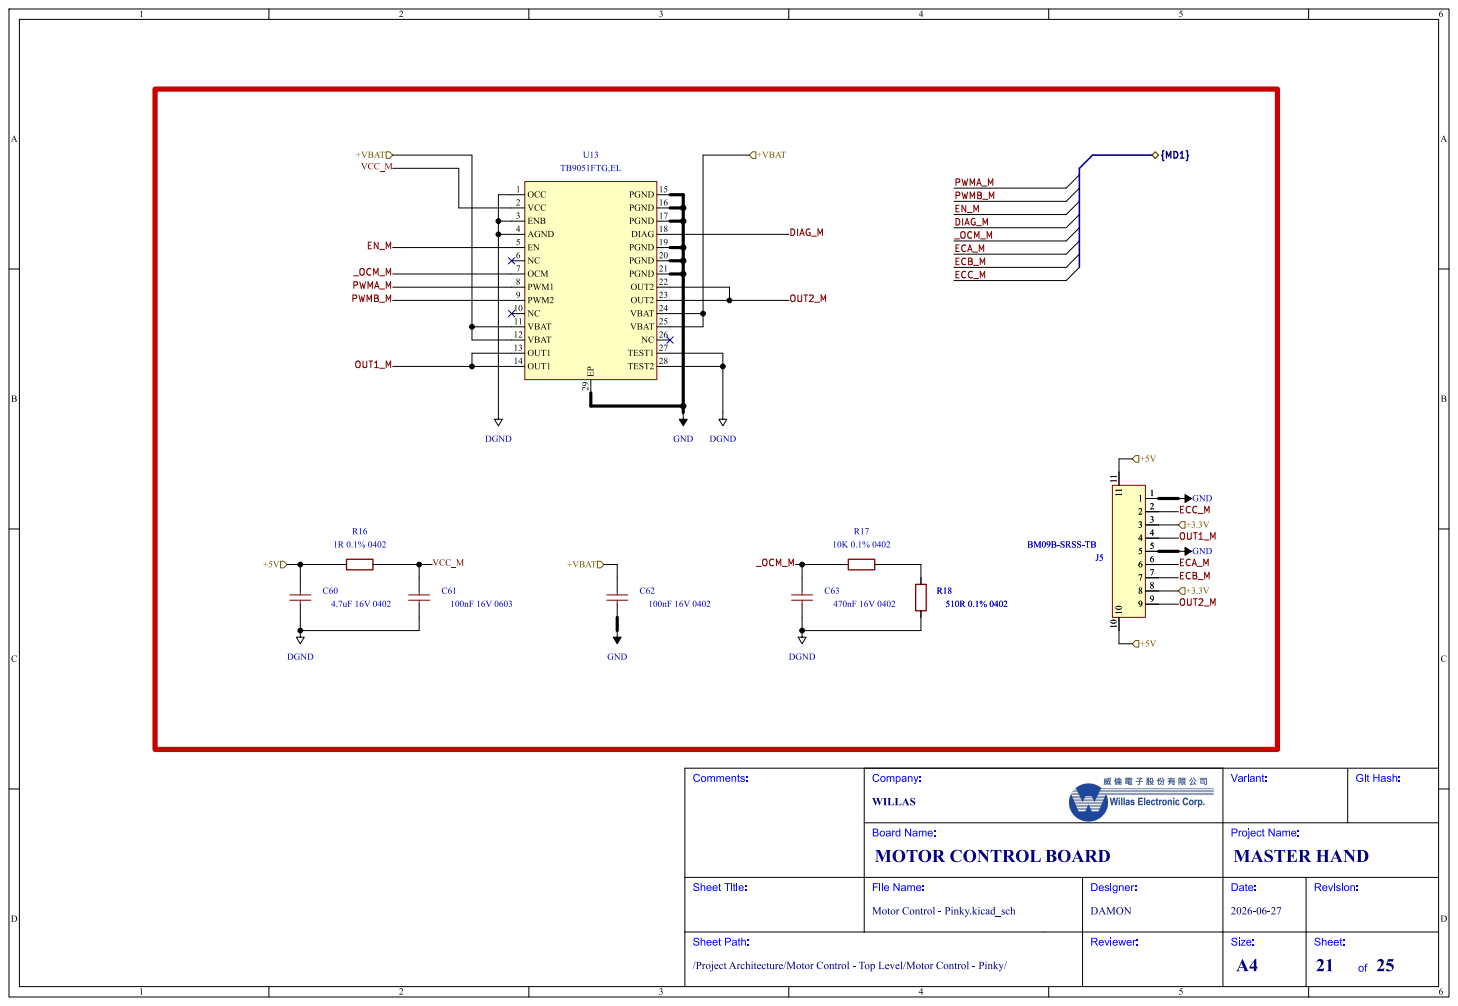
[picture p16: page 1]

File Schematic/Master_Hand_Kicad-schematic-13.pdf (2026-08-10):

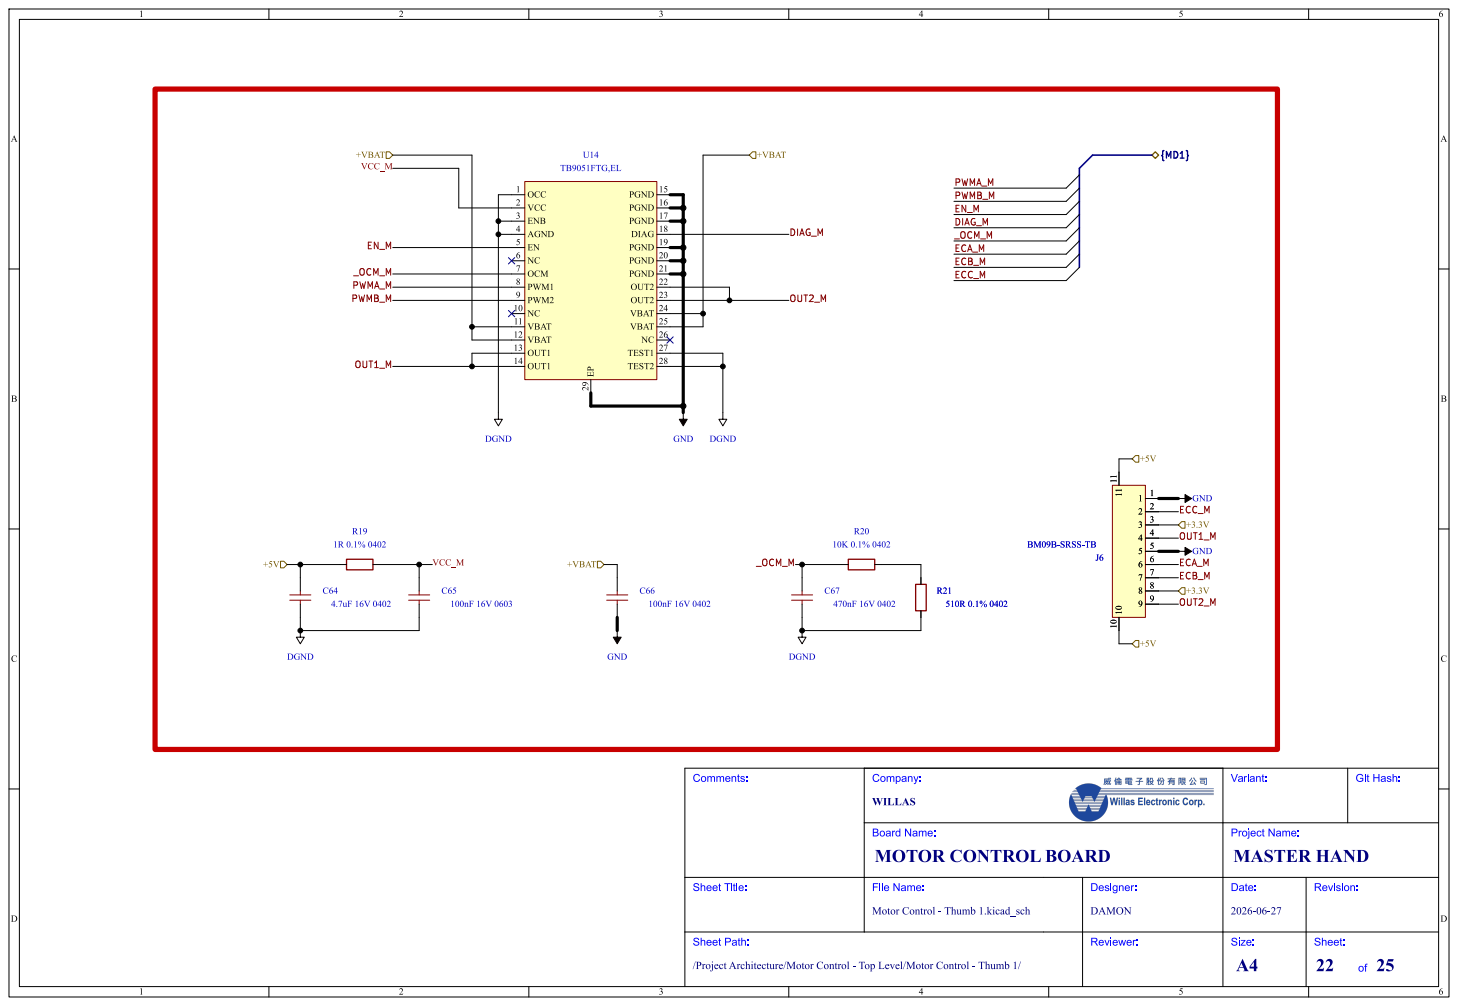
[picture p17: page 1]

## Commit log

2026-06-23 [23/06/2026] Block Diagram update
    [Block Diagram.kicad_sch, Master_Hand_Kicad.kicad_sch, Power - Sequencing.kicad_sch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]
2026-06-24 [24/06/2026] Block Diagram Update
    [Block Diagram.kicad_sch, Master_Hand_Kicad.kicad_sch, Project Architecture.kicad_sch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]
2026-06-24 [25/06/2026][MCU-POWER] Update
    [Block Diagram.kicad_sch, MCU - POWER.kicad_sch, Project Architecture.kicad_sch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]
2026-06-25 [25/06/2025][Block Diagram] Update
    [Block Diagram.kicad_sch]
2026-06-25 [25/06/2025][MCU - IOs] Update
    [Interface - FD-CAN.kicad_sch, Interface - Interconnects.kicad_sch, Interface - RS-422.kicad_sch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]
2026-06-26 [26/06/2026][MCU - IOs] Update
    [MCU - IOs.kicad_sch, MCU - POWER.kicad_sch, Project Architecture.kicad_sch]
2026-07-01 [01/07/2026][MCU - IOs] Update
    [Block Diagram.kicad_sch, Interface - FD-CAN.kicad_sch, Interface - Interconnects.kicad_sch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]
2026-07-07 [07/07/2026][Power - Generation] Update
    [Block Diagram.kicad_sch, Power - Generation.kicad_sch]
2026-07-30 Update Power Generation Schematic
    [Block Diagram.kicad_sch, MCU - IOs.kicad_sch, MCU - POWER.kicad_sch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]
2026-07-31 Update Power Connector & Motor Control Schematic
    [Interface - FD-CAN.kicad_sch, Interface - Interconnects.kicad_sch, Interface - RS-422.kicad_sch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]
2026-08-10 Update Schematic
    [MCU - IOs.kicad_sch, Master_Hand_Kicad.kicad_pcb, Master_Hand_Kicad.kicad_sch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]
2026-08-10 Fix schematic filename case
    [MCU - Power.kicad_sch]
2026-08-10 Update Outputs
    [Master_Hand_Kicad-(L1-L6)_drill_table.csv, Master_Hand_Kicad-bom.csv, Master_Hand_Kicad-components_count.csv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]
